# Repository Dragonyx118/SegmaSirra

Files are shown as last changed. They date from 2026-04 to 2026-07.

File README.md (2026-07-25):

# 🌿 SegmaSirra — Smart Solar Greenhouse

<p align="center">
<b>Un'ecosistema IoT completo per la gestione, l'irrigazione e il monitoraggio remoto di una serra automatizzata e autosufficiente.</b>
</p>

<p align="center">





</p>

<br />

<p align="center">
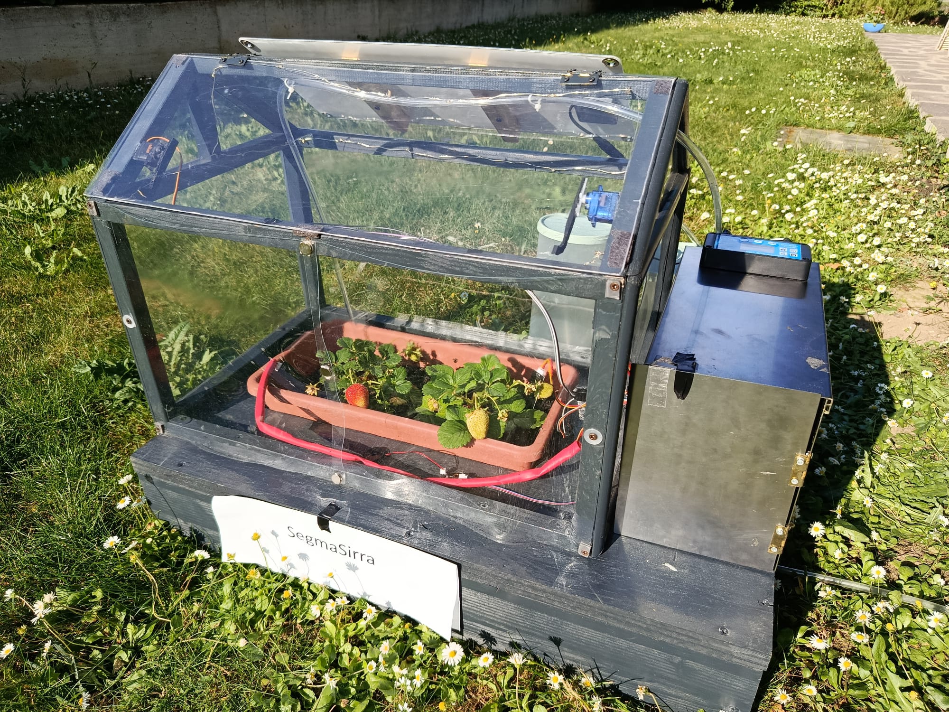
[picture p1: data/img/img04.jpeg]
SegmaSirra Main Overview

</p>

---

## 📌 Indice
- [Cos'è SegmaSirra?](#-cosè-segmasirra)
- [Galleria Fotografica](#-galleria-fotografica)
- [Architettura del Sistema](#-architettura-del-sistema)
- [Specifiche Hardware](#-specifiche-hardware)
- [Funzionalità nel Dettaglio](#-funzionalità-nel-dettaglio)
- [Struttura della Repository](#-struttura-della-repository)
- [Guida all'Installazione](#-guida-allinstallazione)
- [1. Firmware (ESP32)](#1-firmware-esp32)
- [2. App Android](#2-app-android)
- [Roadmap & Sviluppi Futuri](#-roadmap--sviluppi-futuri)
- [Licenza](#-licenza)

---

## 🍃 Cos'è SegmaSirra?

**SegmaSirra** è una serra domotica completamente **autosufficiente dal punto di vista energetico**, progettata per ottimizzare la crescita delle piante senza richiedere interventi umani continui.
**SegmaSirra** è una serra domotica completamente **autosufficiente**, progettata per ottimizzare la crescita delle piante senza richiedere interventi umani continui.

Grazie al microcontrollore **ESP32-WROOM-32** e all'alimentazione integrata da pannello solare a 12V, il sistema analizza costantemente i parametri ambientali (temperatura, umidità del suolo e dell'aria, luminosità) ed esegue azioni correttive automatiche. Tutto l'ecosistema è interfacciato in tempo reale con un'app Android dedicata tramite connessione Wi-Fi.

🌐 **Sito del Progetto:** [dragonyx118.github.io/SegmaSirra-Web/](https://dragonyx118.github.io/SegmaSirra-Web/)

---

## 📱 App Android (SegmaIpp)

Il controllo e il monitoraggio remoto della serra avvengono tramite un'applicazione Android sviluppata ad hoc e ospitata in una repository dedicata:

👉 **Repository dell'App:** [**Dragonyx118/SegmaIpp**](https://github.com/Dragonyx118/SegmaIpp)

### Caratteristiche dell'App:
* **Dashboard in tempo reale:** Visualizzazione dei dati di temperatura, umidità ambientale, umidità del terreno e luminosità.
* **Controllo remoto manuale:** Attivazione forzata dell'irrigazione, gestione delle luci notturne ed apertura/chiusura del tetto via Wi-Fi.
* **Notifiche ed avvisi:** Monitoraggio dello stato delle cisterne e della batteria.

---

## 📸 Galleria Fotografica
## 📸 Galleria

<div align="center">
<table>
<tr>
 <td align="center" width="50%">
   <br />
   <b></b>
 </td>
 <td align="center" width="50%">
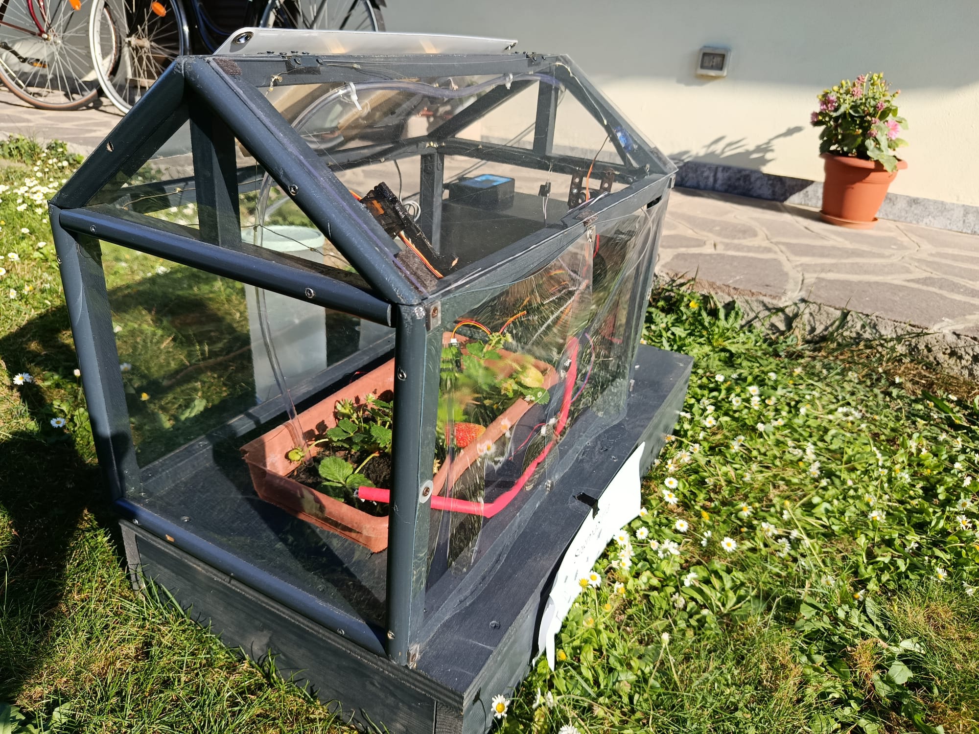
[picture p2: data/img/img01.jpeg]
   <br />
   <b></b>
 </td>
</tr>
<tr>
 <td align="center" width="50%">
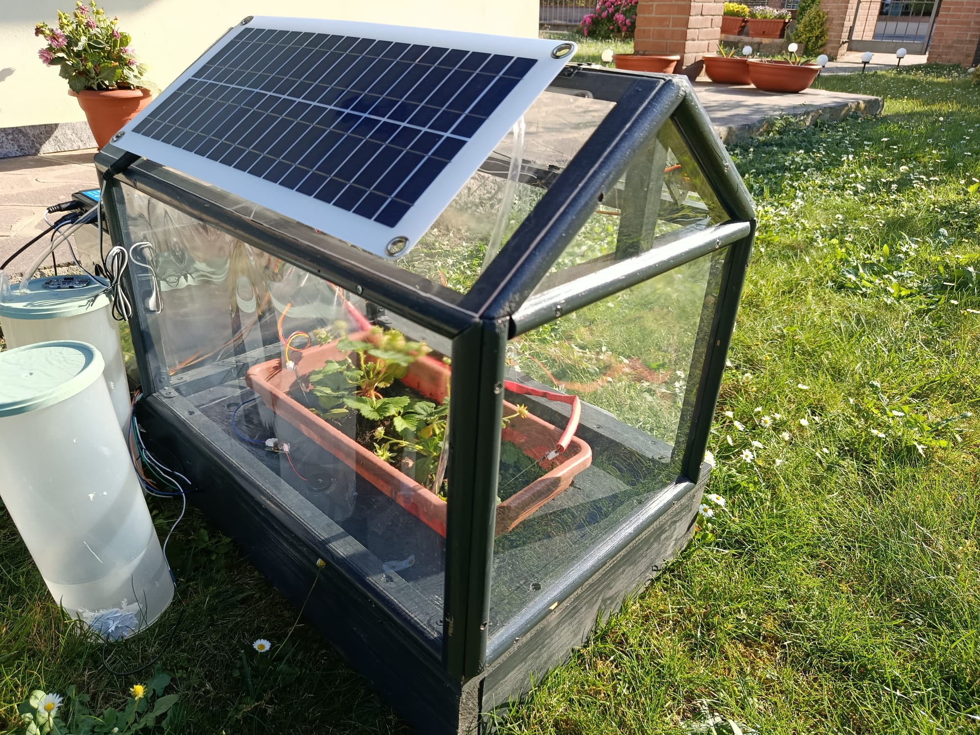
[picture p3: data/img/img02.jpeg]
   <br />
   <b></b>
 </td>
 <td align="center" width="50%">
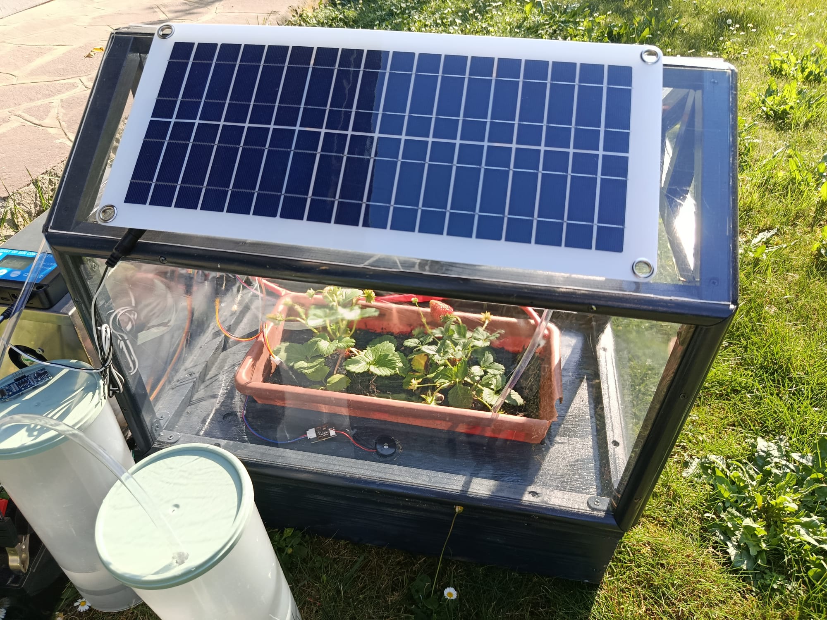
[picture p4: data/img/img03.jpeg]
   <br />
   <b></b>
 </td>
</tr>
</table>
</div>

---

## ⚡ Architettura del Sistema

```text
              +----------------------------------+
              |     Pannello Solare + Reg.      |
              +-----------------+----------------+
                                |
                                v
                      +------------------+
                      | Batteria AGM 12V |
                      +--------+---------+
                                |
                                v
+--------------------------------+--------------------------------+
|                       Modulo ESP32-WROOM-32                      |
|                                                                 |
|  [Sensori Clima & Luce]  --->  Elaborazione Data  --->  [Wi-Fi] |
+-------+------------------------+------------------------+-------+
       |                        |                        |
       v                        v                        v
+---------------+        +---------------+        +---------------+
|   Attuatori   |        | Servomotori   |        |  App Android  |
| 2x Ventole    |        | Apertura      |        | Monitoraggio  |
| 2x Pompe 12V  |        | Tetto         |        |  & Comandi    |
| Luci Notturne |        +---------------+        +---------------+

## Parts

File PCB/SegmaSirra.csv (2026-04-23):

Reference | Qty | Value | DNP | Exclude from BOM | Exclude from Board | Footprint | Datasheet
C1 | 1 | 100nF |  |  |  | Capacitor_THT:C_Disc_D5.0mm_W2.5mm_P5.00mm | ~
C2 | 1 | 470µF 16V |  |  |  | Capacitor_THT:CP_Radial_D8.0mm_P3.50mm | ~
D1 | 1 | LED |  |  |  | LED_THT:LED_D5.0mm | ~
D2 | 1 | D |  |  |  | Diode_THT:D_5KPW_P12.70mm_Horizontal | ~
J1 | 1 | 12V out |  |  |  | TerminalBlock_Phoenix:TerminalBlock_Phoenix_MKDS-1,5-2_1x02_P5.00mm_Horizontal | ~
J2 | 1 | ScocketEsp32 (1) |  |  |  | Connector_PinSocket_2.54mm:PinSocket_1x19_P2.54mm_Vertical | ~
J3 | 1 | ScocketEsp32 (2) |  |  |  | Connector_PinSocket_2.54mm:PinSocket_1x19_P2.54mm_Vertical | ~
J4 | 1 | 12V in |  |  |  | TerminalBlock_Phoenix:TerminalBlock_Phoenix_MKDS-1,5-2_1x02_P5.00mm_Horizontal | ~
J5 | 1 | 5V out |  |  |  | TerminalBlock_Phoenix:TerminalBlock_Phoenix_MKDS-1,5-2_1x02_P5.00mm_Horizontal | ~
J6 | 1 | Servo1 |  |  |  | Connector_PinSocket_2.54mm:PinSocket_1x03_P2.54mm_Vertical | ~
J7 | 1 | Servo2 |  |  |  | Connector_PinSocket_2.54mm:PinSocket_1x03_P2.54mm_Vertical | ~
J8 | 1 | Umidif1 |  |  |  | Connector_PinSocket_2.54mm:PinSocket_1x03_P2.54mm_Vertical | ~
J9 | 1 | Umidif2 |  |  |  | Connector_PinSocket_2.54mm:PinSocket_1x03_P2.54mm_Vertical | ~
J10 | 1 | ConPompLedCOM |  |  |  | TerminalBlock_Phoenix:TerminalBlock_Phoenix_MKDS-1,5-3_1x03_P5.00mm_Horizontal | ~
J11 | 1 | Conn Vent2 |  |  |  | Connector_JST:JST_PH_B2B-PH-K_1x02_P2.00mm_Vertical | ~
J12 | 1 | Conn Vent1 |  |  |  | Connector_JST:JST_PH_B2B-PH-K_1x02_P2.00mm_Vertical | ~
J13 | 1 | connettore fotoresistore |  |  |  | Connector_PinSocket_2.54mm:PinSocket_1x02_P2.54mm_Vertical | ~
J14 | 1 | ConnSensUltra |  |  |  | Connector_PinSocket_2.54mm:PinSocket_1x04_P2.54mm_Vertical | ~
J15 | 1 | SchermoLCDi2C |  |  |  | Connector_PinSocket_2.54mm:PinSocket_1x04_P2.54mm_Vertical | ~
J16 | 1 | SensTerreno1 |  |  |  | Connector_PinSocket_2.54mm:PinSocket_1x03_P2.54mm_Vertical | ~
J17 | 1 | SensTerreno2 |  |  |  | Connector_PinSocket_2.54mm:PinSocket_1x03_P2.54mm_Vertical | ~
J18 | 1 | Pompa 2 |  |  |  | TerminalBlock_Phoenix:TerminalBlock_Phoenix_MKDS-1,5-2_1x02_P5.00mm_Horizontal | ~
J19 | 1 | ConnRelè |  |  |  | TerminalBlock_Phoenix:TerminalBlock_Phoenix_MKDS-1,5-4_1x04_P5.00mm_Horizontal | ~
J20 | 1 | SHT35 |  |  |  | Connector_PinSocket_2.54mm:PinSocket_1x04_P2.54mm_Vertical | ~
J21 | 1 | USB_A |  |  |  | Connector_PinHeader_2.54mm:PinHeader_1x04_P2.54mm_Vertical | ~
Q1 | 1 | IRLZ44N |  |  |  | Package_TO_SOT_THT:TO-220-3_Vertical | http://www.irf.com/product-info/datasheets/data/irlz44n.pdf
R1 | 1 | 220 Ohm |  |  |  | Resistor_THT:R_Axial_DIN0207_L6.3mm_D2.5mm_P7.62mm_Horizontal | ~
R2 | 1 | 100 ohm |  |  |  | Resistor_THT:R_Axial_DIN0207_L6.3mm_D2.5mm_P7.62mm_Horizontal | ~
R3 | 1 | 10k Ohm |  |  |  | Resistor_THT:R_Axial_DIN0207_L6.3mm_D2.5mm_P7.62mm_Horizontal | ~
R4 | 1 | 10kOhm |  |  |  | Resistor_THT:R_Axial_DIN0207_L6.3mm_D2.5mm_P7.62mm_Horizontal | ~
R5 | 1 | 4,7k / 10k Ohm |  |  |  | Resistor_THT:R_Axial_DIN0207_L6.3mm_D2.5mm_P7.62mm_Horizontal | ~
SW1 | 1 | SW_SPDT |  |  |  | Button_Switch_THT:SW_Slide-03_Wuerth-WS-SLTV_10x2.5x6.4_P2.54mm | ~
TP1 | 1 | GND |  |  |  | TestPoint:TestPoint_Pad_D1.5mm | ~
TP2 | 1 | 12V |  |  |  | TestPoint:TestPoint_Pad_D1.5mm | ~
TP3 | 1 | 5V |  |  |  | TestPoint:TestPoint_Pad_D1.5mm | ~
U1 | 1 | DHT11 |  |  |  | Sensor:Aosong_DHT11_5.5x12.0_P2.54mm | http://akizukidenshi.com/download/ds/aosong/DHT11.pdf

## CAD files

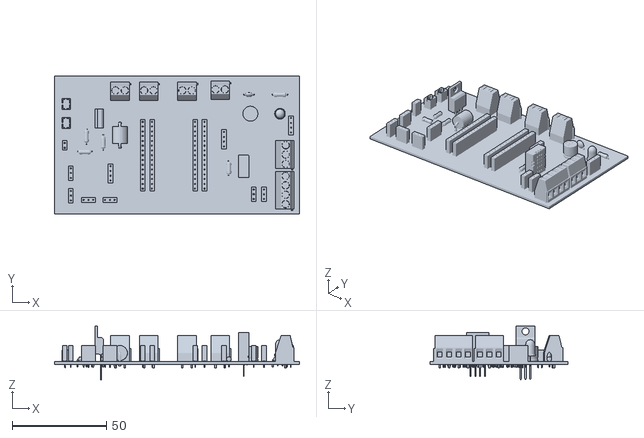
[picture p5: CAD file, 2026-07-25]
PCB/SegmaSirra.stl
130.3 x 73.4 x 28.5

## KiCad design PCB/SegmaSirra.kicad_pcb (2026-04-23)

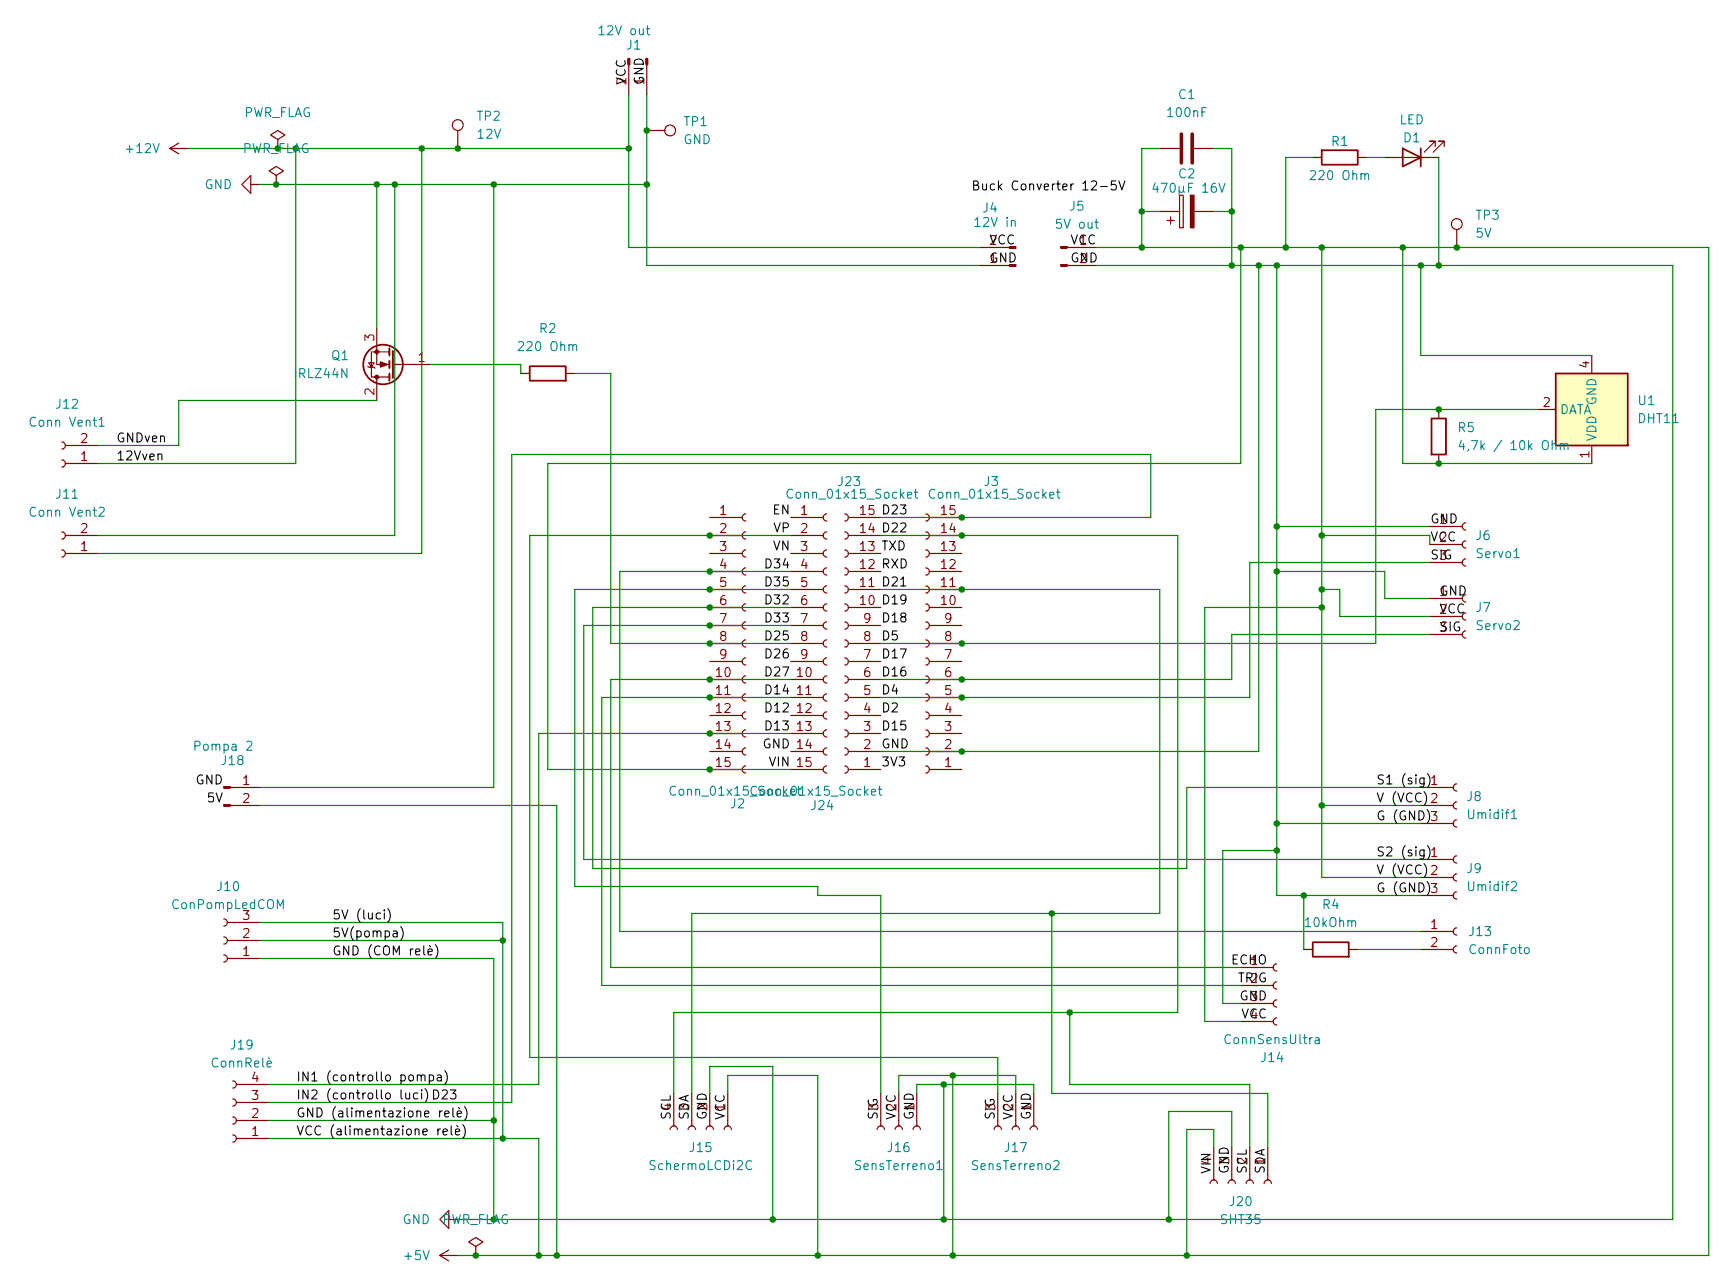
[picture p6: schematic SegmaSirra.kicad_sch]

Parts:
C1: 100nF; C_Disc_D5.0mm_W2.5mm_P5.00mm
C2: 470µF 16V; CP_Radial_D8.0mm_P3.50mm
D1: LED; LED_D5.0mm
J1: 12V out; TerminalBlock_Phoenix_MKDS-1,5-2_1x02_P5.00mm_Horizontal
J2, J3, J23, J24: Conn_01x15_Socket; PinSocket_1x15_P2.54mm_Vertical
J4: 12V in; TerminalBlock_Phoenix_MKDS-1,5-2_1x02_P5.00mm_Horizontal
J5: 5V out; TerminalBlock_Phoenix_MKDS-1,5-2_1x02_P5.00mm_Horizontal
J6: Servo1; PinSocket_1x03_P2.54mm_Vertical
J7: Servo2; PinSocket_1x03_P2.54mm_Vertical
J8: Umidif1; PinSocket_1x03_P2.54mm_Vertical
J9: Umidif2; PinSocket_1x03_P2.54mm_Vertical
J10: ConPompLedCOM; TerminalBlock_Phoenix_MKDS-1,5-3_1x03_P5.00mm_Horizontal
J11: Conn Vent2; JST_PH_B2B-PH-K_1x02_P2.00mm_Vertical
J12: Conn Vent1; JST_PH_B2B-PH-K_1x02_P2.00mm_Vertical
J13: ConnFoto; PinSocket_1x02_P2.54mm_Vertical
J14: ConnSensUltra; PinSocket_1x04_P2.54mm_Vertical
J15: SchermoLCDi2C; PinSocket_1x04_P2.54mm_Vertical
J16: SensTerreno1; PinSocket_1x03_P2.54mm_Vertical
J17: SensTerreno2; PinSocket_1x03_P2.54mm_Vertical
J18: Pompa 2; TerminalBlock_Phoenix_MKDS-1,5-2_1x02_P5.00mm_Horizontal
J19: ConnRelè; TerminalBlock_Phoenix_MKDS-1,5-4_1x04_P5.00mm_Horizontal
J20: SHT35; PinSocket_1x04_P2.54mm_Vertical
Q1: IRLZ44N; TO-220-3_Vertical
R1, R2: 220 Ohm; R_Axial_DIN0207_L6.3mm_D2.5mm_P7.62mm_Horizontal
R4: 10kOhm; R_Axial_DIN0207_L6.3mm_D2.5mm_P7.62mm_Horizontal
R5: 4,7k / 10k Ohm; R_Axial_DIN0207_L6.3mm_D2.5mm_P7.62mm_Horizontal
TP1: GND; TestPoint_Pad_D1.5mm
TP2: 12V; TestPoint_Pad_D1.5mm
TP3: 5V; TestPoint_Pad_D1.5mm
U1: DHT11; Aosong_DHT11_5.5x12.0_P2.54mm

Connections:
+5V: C1.1, C2.1, J2.15, J5.1, J6.2, J7.2, J8.2, J9.2, J10.2, J10.3, J14.4, J15.1, J16.2, J17.2, J18.2, J19.1, J20.4, J24.15, R1.2, R5.2, TP3.1, U1.1 (VDD)
+12V: J1.2, J4.2, J11.1, J12.1, TP2.1
/3V3: J23.1
/D2: J23.4
/D4: J3.5, J6.3, J23.5
/D5: J3.8, J23.8, R5.1, U1.2 (DATA)
/D12: J24.12
/D13: J2.13, J19.4, J24.13
/D14: J2.11, J14.2, J24.11
/D15: J23.3
/D16: J3.6, J7.3, J23.6
/D17: J23.7
/D18: J23.9
/D19: J23.10
/D21: J3.11, J15.3, J20.1, J23.11
/D22: J3.14, J15.4, J20.2, J23.14
/D23: J3.15, J19.3, J23.15
/D25: J2.8, J24.8, R2.2
/D26: J24.9
/D27: J2.10, J14.1, J24.10
/D32: J2.6, J8.1, J24.6
/D33: J2.7, J9.1, J24.7
/D34: J2.4, J13.1, J24.4
/D35: J2.5, J16.3, J24.5
/EN: J24.1
/GNDven: J12.2, Q1.2 (D)
/RXD: J23.12
/TXD: J23.13
/VN: J24.3
/VP: J2.2, J17.3, J24.2
GND: C1.2, C2.2, D1.1 (K), J1.1, J3.2, J4.1, J5.2, J6.1, J7.1, J8.3, J9.3, J10.1, J11.2, J14.3, J15.2, J16.1, J17.1, J18.1, J19.2, J20.3, J23.2, J24.14, Q1.3 (S), R4.1, TP1.1, U1.4 (GND)
unnamed: D1.2 (A), R1.1
unnamed: J13.2, R4.2
unnamed: Q1.1 (G), R2.1

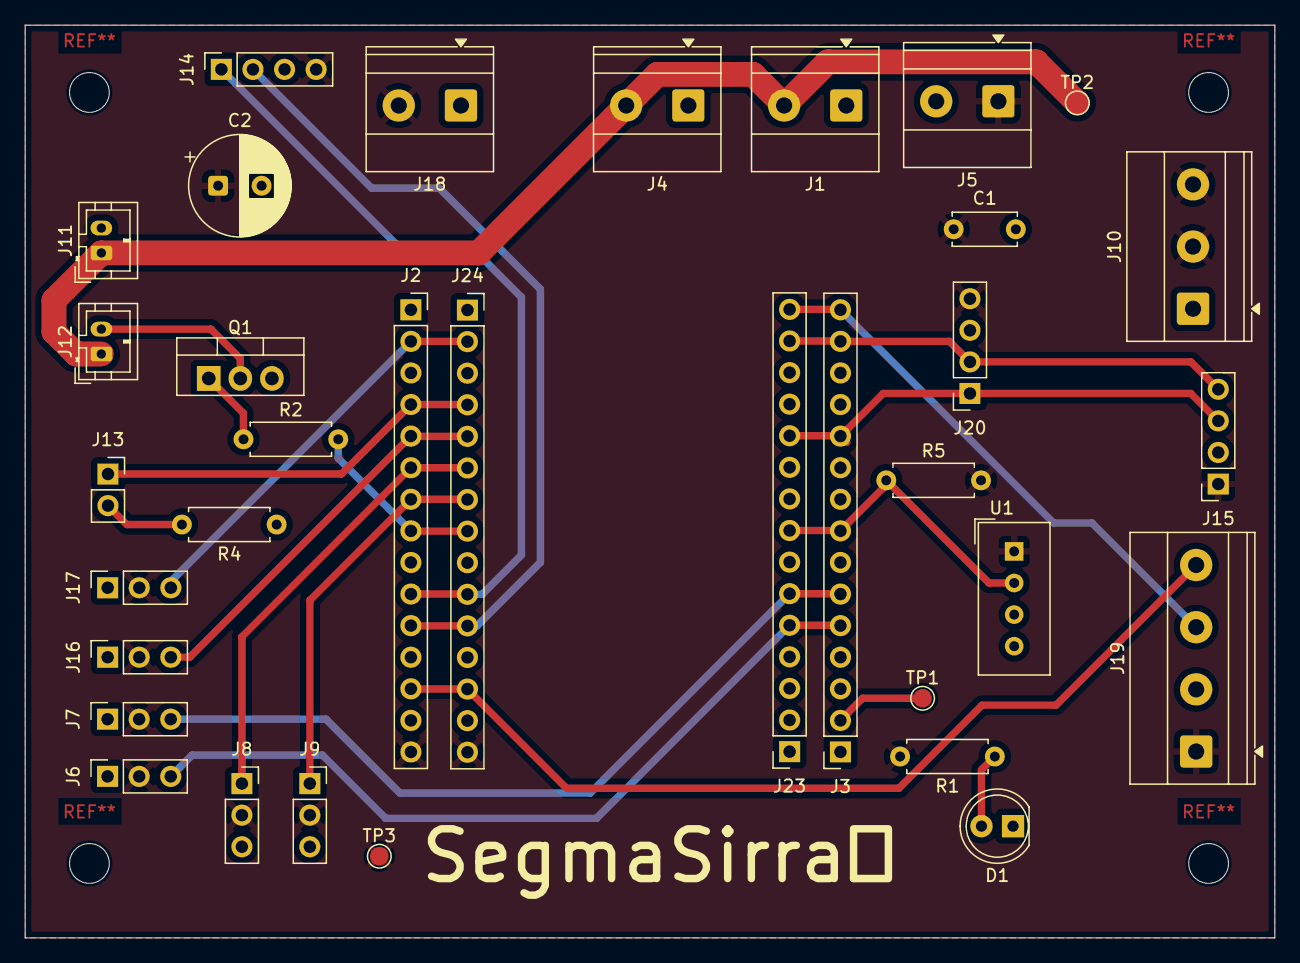
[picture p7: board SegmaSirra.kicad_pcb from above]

Board: 2 copper layers, 100.5 x 73.4 mm, 34 parts (0 on the bottom side), 22 nets.

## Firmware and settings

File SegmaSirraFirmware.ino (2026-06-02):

// ============================================================
// SegmaSirra -6.7 V senza delay bloccanti
// DEBUG VERSION — ultrasuoni con pulseIn (funzionante) ogni 7s
// MODIFICA: servo tetto con movimento graduale (~2s) via FreeRTOS
// ============================================================

#include <Arduino.h>
#include <ESP32Servo.h>
#include <Wire.h>
#include <LiquidCrystal_I2C.h>
#include <WiFi.h>
#include <HTTPClient.h>
#include <DHT.h>
#include <ArduinoJson.h>
#include <Adafruit_SHT4x.h>

// ============================================================
// --- DEBUG CONFIG ---
// ============================================================
#define DEBUG_ULTRASUONI   true
#define DEBUG_SENSORI      true
#define DEBUG_FIREBASE     true
#define DEBUG_WIFI         true
#define DEBUG_ATTUATORI    true
#define DEBUG_LCD          false
#define DEBUG_LOOP_TIMING  false

#define DBG_US(...)   do { if (DEBUG_ULTRASUONI) { Serial.print("[US]   "); Serial.printf(__VA_ARGS__); } } while(0)
#define DBG_SEN(...)  do { if (DEBUG_SENSORI)    { Serial.print("[SEN]  "); Serial.printf(__VA_ARGS__); } } while(0)
#define DBG_FB(...)   do { if (DEBUG_FIREBASE)   { Serial.print("[FB]   "); Serial.printf(__VA_ARGS__); } } while(0)
#define DBG_WIFI(...) do { if (DEBUG_WIFI)       { Serial.print("[WIFI] "); Serial.printf(__VA_ARGS__); } } while(0)
#define DBG_ATT(...)  do { if (DEBUG_ATTUATORI)  { Serial.print("[ATT]  "); Serial.printf(__VA_ARGS__); } } while(0)
#define DBG_LCD(...)  do { if (DEBUG_LCD)        { Serial.print("[LCD]  "); Serial.printf(__VA_ARGS__); } } while(0)
#define DBG_LOOP(...) do { if (DEBUG_LOOP_TIMING){ Serial.print("[LOOP] "); Serial.printf(__VA_ARGS__); } } while(0)

// --- COSTANTI FISICHE ---
const float VELOCITA_SUONO_CM_US = 0.034f;
const float TANK_HEIGHT          = 21.37f;
const float SOGLIA_ACQUA_MINIMA  = 10.0f;

// --- COSTANTI CALIBRAZIONE ACQUA ---
const float DIST_PIENA = 4.56f;    // cm quando tanica piena
const float DIST_VUOTA = 16.37f;   // cm quando rimangono 5cm (= 0% utile)

// --- COSTANTI TIMING (ms) ---
const unsigned long INTERVALLO_SENSORI    = 500;
const unsigned long INTERVALLO_LCD        = 3000;
const unsigned long INTERVALLO_FIREBASE   = 1000;
const unsigned long INTERVALLO_COMANDI    = 500;
const unsigned long INTERVALLO_WIFI_CHECK = 30000;
const unsigned long DHT_WARMUP_MS        = 2000;

// --- ULTRASUONI ---
const unsigned long INTERVALLO_ULTRASUONI = 7000;
const int           CAMPIONI_ULTRASUONI   = 3;
const unsigned long PULSIN_TIMEOUT_US     = 30000;
const unsigned long PAUSA_TRA_PING_MS     = 50;

// --- SERVO TETTO ---
// Aperto:  servoA (pin 4) = 90°,  servoB (pin 16) = 90°
// Chiuso:  servoA (pin 4) = 0°,   servoB (pin 16) = 180°
const int SERVO_A_APERTO  = 0;
const int SERVO_B_APERTO  = 180;
const int SERVO_A_CHIUSO  = 90;
const int SERVO_B_CHIUSO  = 90;
// Durata totale del movimento in ms (~2 secondi).
// Con 90 step massimi da 1° e SERVO_STEP_DELAY_MS = 22ms -> 90 * 22 = 1980ms ≈ 2s
const unsigned long SERVO_STEP_DELAY_MS = 22;

// --- PESI MEDIA PONDERATA TEMP/HUM ---
const float PESO_DHT = 0.3f;
const float PESO_SHT = 0.7f;

// --- CALIBRAZIONE LUCE ---
const int LUCE_MIN = 2000;
const int LUCE_MAX = 4095;

// --- PIN ---
const int luci            = 23;
const int sensoreTerreno  = 35;
const int sensoreTerreno2 = 36;
const int trigPin         = 14;
const int echoPin         = 27;
const int lightPin        = 34;
const int umidificatore1  = 32;
const int umidificatore2  = 33;
const int ventolaSerra    = 25;
const int ventolaScatola  = 26;
const int pompa2          = 13;

// ============================================================
// --- VARIABILI GLOBALI ---
// ============================================================

struct SensorData {
    float temperature;
    float humidity;
    int   soilMoisture;
    bool  valid;
};
SensorData lastSensorData = { -99.0f, -99.0f, 0, false };
float      lastWaterLevel = -1.0f;
int        lastLightPct   = 0;

unsigned long loopCount  = 0;
unsigned long usAvvii    = 0;
unsigned long usSuccessi = 0;
unsigned long usErrori   = 0;
unsigned long fbInvii    = 0;
unsigned long fbErrori   = 0;

unsigned long lastSensorRead    = 0;
unsigned long lastDisplayUpdate = 0;
unsigned long lastSendData      = 0;
unsigned long lastCommandCheck  = 0;
unsigned long lastWifiCheck     = 0;

bool roofOpen = false;

// --- Task servo: stato condiviso ---
// servoTargetOpen viene scritto dal loop, letto dal task servo.
// volatile + SemaphoreHandle per accesso sicuro inter-task.
volatile bool servoTargetOpen    = false;  // posizione target richiesta
volatile bool servoMoving        = false;  // true mentre il task sta muovendo
SemaphoreHandle_t servoMutex     = NULL;

#define DHTPIN  5
#define DHTTYPE DHT11
DHT dht(DHTPIN, DHTTYPE);
unsigned long dhtReadyAt = 0;

Adafruit_SHT4x sht45 = Adafruit_SHT4x();
bool sht45Ok = false;

Servo servoA;
Servo servoB;
const int servoAPin = 4;
const int servoBPin = 16;

#define LCD_ADDR 0x27
LiquidCrystal_I2C lcd(LCD_ADDR, 16, 2);

const char* ssid               = "LAPTOP1234";
const char* password           = "12345678";
const char* firebaseCmdUrl     = "https://serra-d44cc-default-rtdb.europe-west1.firebasedatabase.app/serra/commands.json";
const char* firebaseSensorsUrl = "https://serra-d44cc-default-rtdb.europe-west1.firebasedatabase.app/serra/sensors.json";

// ============================================================
// --- WIFI SM ---
// ============================================================
enum WiFiStato {
    WIFI_OK, WIFI_RECONNECTING, WIFI_FALLBACK_SCAN,
    WIFI_FALLBACK_WAIT_SSID, WIFI_FALLBACK_WAIT_PASS, WIFI_FALLBACK_CONNECTING
};
struct WiFiSM {
    WiFiStato     stato         = WIFI_OK;
    int           tentativi     = 0;
    unsigned long tStato        = 0;
    String        nuovoSSID     = "";
    String        nuovaPassword = "";
} wifiSM;

// ============================================================
// --- TASK FREERTOS: ULTRASUONI (Core 0) ---
// ============================================================
TaskHandle_t taskUltrasuoniHandle = NULL;

void taskUltrasuoni(void* param) {
    DBG_US("Task avviato su Core %d\n", xPortGetCoreID());
    for (;;) {
        vTaskDelay(pdMS_TO_TICKS(INTERVALLO_ULTRASUONI));

        usAvvii++;
        float somma = 0.0f;
        int   validi = 0;

        DBG_US("--- Inizio misura #%lu (campioni=%d) ---\n", usAvvii, CAMPIONI_ULTRASUONI);

        for (int i = 0; i < CAMPIONI_ULTRASUONI; i++) {
            digitalWrite(trigPin, LOW);
            delayMicroseconds(4);
            digitalWrite(trigPin, HIGH);
            delayMicroseconds(10);
            digitalWrite(trigPin, LOW);

            long duration = pulseIn(echoPin, HIGH, PULSIN_TIMEOUT_US);

            if (duration == 0) {
                DBG_US("  Campione %d/%d: TIMEOUT\n", i + 1, CAMPIONI_ULTRASUONI);
            } else {
                float dist   = duration * VELOCITA_SUONO_CM_US / 2.0f;
                float livello = constrain(
                    (DIST_VUOTA - dist) / (DIST_VUOTA - DIST_PIENA) * 100.0f,
                    0.0f, 100.0f
                );
                somma += livello;
                validi++;
                DBG_US("  Campione %d/%d: %ldus -> %.1fcm -> %.1f%%\n",
                       i + 1, CAMPIONI_ULTRASUONI, duration, dist, livello);
            }

            if (i < CAMPIONI_ULTRASUONI - 1) {
                vTaskDelay(pdMS_TO_TICKS(PAUSA_TRA_PING_MS));
            }
        }

        if (validi > 0) {
            lastWaterLevel = somma / validi;
            usSuccessi++;
            DBG_US("OK: media=%.1f%% (%d/%d validi) [tot ok=%lu err=%lu]\n",
                   lastWaterLevel, validi, CAMPIONI_ULTRASUONI, usSuccessi, usErrori);
        } else {
            usErrori++;
            lastWaterLevel = -1.0f;
            DBG_US("ERRORE: 0 campioni validi [tot ok=%lu err=%lu]\n", usSuccessi, usErrori);
        }
    }
}

// ============================================================
// --- TASK FREERTOS: SERVO TETTO (Core 1) ---
//
// Gira su Core 1 insieme al loop, ma con priorità 2 (loop ha 1).
// Aspetta una notifica dal loop tramite xTaskNotifyGive().
// Quando riceve la notifica legge servoTargetOpen e muove i servo
// gradualmente step da 1° con delay di SERVO_STEP_DELAY_MS ms.
// Il loop non viene bloccato perché il delay è interno al task.
// ============================================================
TaskHandle_t taskServoHandle = NULL;

void taskServo(void* param) {
    DBG_ATT("Task servo avviato su Core %d\n", xPortGetCoreID());

    // Posizione corrente stimata (inizializzata su chiuso)
    int posA = SERVO_A_CHIUSO;
    int posB = SERVO_B_CHIUSO;

    for (;;) {
        // Aspetta finché il loop chiama xTaskNotifyGive(taskServoHandle)
        ulTaskNotifyTake(pdTRUE, portMAX_DELAY);

        // Leggi target con mutex
        bool targetOpen;
        xSemaphoreTake(servoMutex, portMAX_DELAY);
        targetOpen   = servoTargetOpen;
        servoMoving  = true;
        xSemaphoreGive(servoMutex);

        int targetA = targetOpen ? SERVO_A_APERTO : SERVO_A_CHIUSO;
        int targetB = targetOpen ? SERVO_B_APERTO : SERVO_B_CHIUSO;

        DBG_ATT("Servo: movimento %s | A: %d->%d  B: %d->%d\n",
                targetOpen ? "APERTO" : "CHIUSO", posA, targetA, posB, targetB);

        // Calcola quanti step servono (max tra i due servo)
        int stepsA = abs(targetA - posA);
        int stepsB = abs(targetB - posB);
        int steps  = max(stepsA, stepsB);

        for (int i = 1; i <= steps; i++) {
            // Interpolazione lineare per entrambi i servo
            // Usa arrotondamento corretto per evitare jitter all'ultimo step
            int newA = posA + (int)roundf((float)(targetA - posA) * i / steps);
            int newB = posB + (int)roundf((float)(targetB - posB) * i / steps);

            servoA.write(newA);
            servoB.write(newB);

            // Delay non bloccante per il task (non tocca il loop)
            vTaskDelay(pdMS_TO_TICKS(SERVO_STEP_DELAY_MS));

            // Se nel frattempo è arrivato un nuovo target, interrompi
            // e lascia che il task riparta con il nuovo valore
            if (ulTaskNotifyTake(pdTRUE, 0) > 0) {
                // Aggiorna posizione corrente al punto dove ci siamo fermati
                posA = newA;
                posB = newB;
                DBG_ATT("Servo: movimento interrotto a step %d/%d (nuovo comando)\n", i, steps);
                // Re-inserisci la notifica così il for esterno la riceve
                xTaskNotifyGive(taskServoHandle);
                goto next_command;
            }
        }

        // Movimento completato: scrivi esattamente il target
        servoA.write(targetA);
        servoB.write(targetB);
        posA = targetA;
        posB = targetB;
        DBG_ATT("Servo: %s completato (A=%d B=%d)\n",
                targetOpen ? "APERTO" : "CHIUSO", posA, posB);

        next_command:
        xSemaphoreTake(servoMutex, portMAX_DELAY);
        servoMoving = false;
        xSemaphoreGive(servoMutex);
    }
}

// ============================================================
// --- FUNZIONE HELPER: richiedi movimento tetto ---
// Chiamala al posto di servoA.write() / servoB.write() diretto.
// È thread-safe e non bloccante.
// ============================================================
void setRoof(bool open) {
    xSemaphoreTake(servoMutex, portMAX_DELAY);
    servoTargetOpen = open;
    xSemaphoreGive(servoMutex);

    // Notifica il task servo di muoversi
    xTaskNotifyGive(taskServoHandle);

    // Aggiorna subito lo stato logico (non aspettare il completamento fisico)
    roofOpen = open;
    DBG_ATT("Tetto: richiesta %s\n", open ? "APERTURA" : "CHIUSURA");
}

// ============================================================
// --- PROTOTIPI ---
// ============================================================
void connectWiFiBlocking();
void tickWiFiSM();
void sendToFirebase(const SensorData& s, float waterLevel, int lightPct);
void updateLCD(float umiditaTerreno, float acqua, float temp, float umidita, int luce);
void readFirebaseCommands();
void startIrrigation(float waterLevel);
void stopIrrigation();
void startHumidifier();
void stopHumidifier();
void startFan();
void stopFan();
SensorData readNewSensors();
void printDebugSummary();
void scanI2C();
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
void loop() {
    unsigned long now = millis();
    loopCount++;

    tickWiFiSM();

    if (now - lastWifiCheck >= INTERVALLO_WIFI_CHECK) {
        lastWifiCheck = now;
        if (WiFi.status() != WL_CONNECTED && wifiSM.stato == WIFI_OK) {
            DBG_WIFI("Connessione persa!\n");
            WiFi.disconnect();
            WiFi.begin(ssid, password);
            wifiSM.stato     = WIFI_RECONNECTING;
            wifiSM.tentativi = 0;
            wifiSM.tStato    = now;
        } else if (WiFi.status() == WL_CONNECTED) {
            DBG_WIFI("Check OK - IP:%s RSSI:%ddBm heap:%d\n",
                     WiFi.localIP().toString().c_str(), WiFi.RSSI(), ESP.getFreeHeap());
        }
    }

    if (now - lastSensorRead >= INTERVALLO_SENSORI) {
        lastSensorRead = now;
        lastSensorData = readNewSensors();

        int luceRaw = analogRead(lightPin);
        lastLightPct = constrain(
            (int)((float)(luceRaw - LUCE_MIN) / (LUCE_MAX - LUCE_MIN) * 100.0f),
            0, 100
        );
        DBG_SEN("Luce: raw=%d -> %d%%\n", luceRaw, lastLightPct);
    }

    if (now - lastDisplayUpdate >= INTERVALLO_LCD) {
        lastDisplayUpdate = now;
        updateLCD(lastSensorData.soilMoisture, lastWaterLevel,
                  lastSensorData.temperature, lastSensorData.humidity, lastLightPct);
        printDebugSummary();
    }

    if (now - lastSendData >= INTERVALLO_FIREBASE) {
        lastSendData = now;
        sendToFirebase(lastSensorData, lastWaterLevel, lastLightPct);
    }

    if (now - lastCommandCheck >= INTERVALLO_COMANDI) {
        lastCommandCheck = now;
        readFirebaseCommands();
    }

    DBG_LOOP("loop #%lu heap=%d\n", loopCount, ESP.getFreeHeap());
}

// ============================================================
// --- RIEPILOGO DEBUG ---
// ============================================================
void printDebugSummary() {
    bool moving;
    xSemaphoreTake(servoMutex, portMAX_DELAY);
    moving = servoMoving;
    xSemaphoreGive(servoMutex);

    Serial.println("\n========== RIEPILOGO ==========");
    Serial.printf("  Uptime: %lus  Loop: %lu  Heap: %d\n",
                  millis() / 1000, loopCount, ESP.getFreeHeap());
    Serial.println("  SENSORI:");
    if (lastSensorData.valid) {
        Serial.printf("    T=%.1f°C  H=%.1f%%\n",
                      lastSensorData.temperature, lastSensorData.humidity);
    } else {
        Serial.println("    T/H: ERRORE");
    }
    Serial.printf("    Suolo=%d%%  Luce=%d%%\n", lastSensorData.soilMoisture, lastLightPct);
    if (lastWaterLevel >= 0) {
        Serial.printf("    Acqua=%.1f%%\n", lastWaterLevel);
    } else {
        Serial.println("    Acqua: in attesa prima misura...");
    }
    Serial.printf("  ULTRASUONI: misure=%lu ok=%lu err=%lu (%.0f%%)\n",
                  usAvvii, usSuccessi, usErrori,
                  usAvvii > 0 ? (float)usSuccessi / usAvvii * 100.0f : 0.0f);
    Serial.printf("  WIFI: %s  RSSI:%ddBm\n",
                  WiFi.status() == WL_CONNECTED ? "OK" : "DISCONNESSO", WiFi.RSSI());
    Serial.printf("  FIREBASE: invii=%lu err=%lu\n", fbInvii, fbErrori);
    Serial.printf("  ATTUATORI: pompa=%s umid=%s/%s ventola=%s luci=%s tetto=%s%s\n",
                  digitalRead(pompa2)         ? "ON" : "OFF",
                  digitalRead(umidificatore1) ? "ON" : "OFF",
                  digitalRead(umidificatore2) ? "ON" : "OFF",
                  digitalRead(ventolaSerra)   ? "ON" : "OFF",
                  digitalRead(luci)           ? "ON" : "OFF",
                  roofOpen                    ? "APERTO" : "CHIUSO",
                  moving                      ? " (in movimento...)" : "");
    Serial.println("================================\n");
}

// ============================================================
// --- SCAN I2C ---
// ============================================================
void scanI2C() {
    Serial.println("[I2C] Scansione dispositivi...");
    int trovati = 0;
    for (byte addr = 1; addr < 127; addr++) {
        Wire.beginTransmission(addr);
        if (Wire.endTransmission() == 0) {
            Serial.printf("[I2C] Dispositivo trovato a 0x%02X%s%s\n", addr,
                          (addr == 0x27 || addr == 0x3F) ? " <- LCD"   : "",
                          (addr == 0x44 || addr == 0x45) ? " <- SHT4x" : "");
            trovati++;
        }
    }
    Serial.printf("[I2C] Totale: %d dispositivo/i\n", trovati);
    if (trovati == 0) Serial.println("[I2C] NESSUNO! Verifica SDA=21 SCL=22");
}

// ============================================================
// --- WIFI BLOCKING ---
// ============================================================
void connectWiFiBlocking() {
    DBG_WIFI("Connessione a '%s'...\n", ssid);
    WiFi.begin(ssid, password);
    unsigned long t0 = millis(), tPoll = millis();
    while (WiFi.status() != WL_CONNECTED && millis() - t0 < 10000) {
        if (millis() - tPoll >= 500) { tPoll = millis(); Serial.print("."); }
    }
    if (WiFi.status() == WL_CONNECTED) {
        DBG_WIFI("\nConnesso! IP:%s RSSI:%ddBm\n",
                 WiFi.localIP().toString().c_str(), WiFi.RSSI());
        wifiSM.stato = WIFI_OK;
    } else {
        DBG_WIFI("\nFallito, avvio fallback\n");
        wifiSM.tStato = millis();
        wifiSM.stato  = WIFI_FALLBACK_SCAN;
    }
}

// ============================================================
// --- WIFI SM ---
// ============================================================
void tickWiFiSM() {
    unsigned long now = millis();
    switch (wifiSM.stato) {
        case WIFI_OK: break;
        case WIFI_RECONNECTING:
            if (now - wifiSM.tStato >= 500) {
                wifiSM.tStato = now; wifiSM.tentativi++;
                if (WiFi.status() == WL_CONNECTED) {
                    DBG_WIFI("Riconnesso!\n"); wifiSM.stato = WIFI_OK;
                } else if (wifiSM.tentativi >= 20) {
                    DBG_WIFI("Riconnessione fallita\n"); wifiSM.stato = WIFI_OK;
                }
            }
            break;
        case WIFI_FALLBACK_SCAN: {
            Serial.println("\n=== CONFIGURAZIONE WIFI MANUALE ===");
            int n = WiFi.scanNetworks();
            for (int i = 0; i < n; i++)
                Serial.printf("  %d) %s (%ddBm)\n", i + 1,
                              WiFi.SSID(i).c_str(), WiFi.RSSI(i));
            Serial.println("Inserisci SSID:");
            wifiSM.stato = WIFI_FALLBACK_WAIT_SSID; wifiSM.tStato = now;
            break;
        }
        case WIFI_FALLBACK_WAIT_SSID:
            if (Serial.available()) {
                wifiSM.nuovoSSID = Serial.readStringUntil('\n');
                wifiSM.nuovoSSID.trim();
                if (wifiSM.nuovoSSID.length() > 0) {
                    Serial.println("Inserisci password:");
                    wifiSM.stato = WIFI_FALLBACK_WAIT_PASS; wifiSM.tStato = now;
                }
            }
            break;
        case WIFI_FALLBACK_WAIT_PASS:
            if (Serial.available()) {
                wifiSM.nuovaPassword = Serial.readStringUntil('\n');
                wifiSM.nuovaPassword.trim();
                wifiSM.stato = WIFI_FALLBACK_CONNECTING;
                wifiSM.tStato = now; wifiSM.tentativi = 0;
                if (wifiSM.nuovaPassword.length() > 0)
                    WiFi.begin(wifiSM.nuovoSSID.c_str(), wifiSM.nuovaPassword.c_str());
                else
                    WiFi.begin(wifiSM.nuovoSSID.c_str());
            } else if (now - wifiSM.tStato >= 30000) {
                wifiSM.stato = WIFI_FALLBACK_CONNECTING;
                wifiSM.tStato = now; wifiSM.tentativi = 0;
                WiFi.begin(wifiSM.nuovoSSID.c_str());
            }
            break;
        case WIFI_FALLBACK_CONNECTING:
            if (now - wifiSM.tStato >= 500) {
                wifiSM.tStato = now; wifiSM.tentativi++;
                if (WiFi.status() == WL_CONNECTED) {
                    DBG_WIFI("Connesso!\n"); wifiSM.stato = WIFI_OK;
                } else if (wifiSM.tentativi >= 30) {
                    DBG_WIFI("Offline\n"); wifiSM.stato = WIFI_OK;
                }
            }
            break;
    }
}
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

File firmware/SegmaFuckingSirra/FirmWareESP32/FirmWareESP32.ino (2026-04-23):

// ============================================================
// SegmaFuckingSirra -67.0 V senza delay bloccanti
// ============================================================

// --- LIBRERIE ---
#include <Arduino.h>
#include <ESP32Servo.h>
#include <Wire.h>
#include <LiquidCrystal_I2C.h>
#include <WiFi.h>
#include <HTTPClient.h>
#include <DHT.h>
#include <ArduinoJson.h>
#include <Adafruit_SHT4x.h>

// --- COSTANTI FISICHE ---
const float VELOCITA_SUONO_CM_US = 0.034f;
const float TANK_HEIGHT          = 30.0f;
const float SOGLIA_ACQUA_MINIMA  = 10.0f;

// --- COSTANTI TIMING (ms) ---
const unsigned long INTERVALLO_SENSORI    = 500;
const unsigned long INTERVALLO_LCD        = 3000;
const unsigned long INTERVALLO_FIREBASE   = 1000;
const unsigned long INTERVALLO_COMANDI    = 500;
const unsigned long INTERVALLO_WIFI_CHECK = 30000;
const unsigned long DHT_WARMUP_MS         = 2000;

// --- COSTANTI ULTRASUONI ---
const int           CAMPIONI_ULTRASUONI   = 3;
const unsigned long PAUSA_TRA_PING_MS     = 35;
const unsigned long TIMEOUT_ECHO_MS       = 30;

// --- PESI MEDIA PONDERATA SENSORI T/H ---
const float PESO_DHT = 0.3f;
const float PESO_SHT = 0.7f;

// --- PIN ---
const int luci            = 23;
const int sensoreTerreno  = 35;
const int sensoreTerreno2 = 36;
const int trigPin         = 14;
const int echoPin         = 27;
const int lightPin        = 34;
const int umidificatore1  = 32;
const int umidificatore2  = 33;
const int ventolaSerra    = 25;
const int ventolaScatola  = 26;
const int pompa2          = 13;

// ============================================================
// --- MACCHINA A STATI: ULTRASUONI NON BLOCCANTE ---
// ============================================================
enum UltrasuoniStato {
    US_IDLE,
    US_TRIGGER_LOW,
    US_TRIGGER_HIGH,
    US_WAIT_ECHO_START,
    US_WAIT_ECHO_END,
    US_PAUSA,
    US_DONE
};

struct UltrasuoniSM {
    UltrasuoniStato stato    = US_IDLE;
    int             campione = 0;
    float           somma    = 0.0f;
    int             validi   = 0;
    unsigned long   tStato   = 0;
    float           risultato= -1.0f;
    bool            pronto   = false;
} usSM;

void startUltrasuoni() {
    usSM.stato    = US_TRIGGER_LOW;
    usSM.campione = 0;
    usSM.somma    = 0.0f;
    usSM.validi   = 0;
    usSM.pronto   = false;
    usSM.tStato   = micros();
    digitalWrite(trigPin, LOW);
}

void tickUltrasuoniSM() {
    if (usSM.stato == US_IDLE || usSM.stato == US_DONE) return;

    switch (usSM.stato) {
        case US_TRIGGER_LOW:
            if (micros() - usSM.tStato >= 2) {
                digitalWrite(trigPin, HIGH);
                usSM.tStato = micros();
                usSM.stato  = US_TRIGGER_HIGH;
            }
            break;

        case US_TRIGGER_HIGH:
            if (micros() - usSM.tStato >= 10) {
                digitalWrite(trigPin, LOW);
                usSM.tStato = millis();
                usSM.stato  = US_WAIT_ECHO_START;
            }
            break;

        case US_WAIT_ECHO_START:
            if (digitalRead(echoPin) == HIGH) {
                usSM.tStato = micros();
                usSM.stato  = US_WAIT_ECHO_END;
            } else if (millis() - usSM.tStato >= TIMEOUT_ECHO_MS) {
                usSM.campione++;
                usSM.tStato = millis();
                usSM.stato  = (usSM.campione < CAMPIONI_ULTRASUONI) ? US_PAUSA : US_DONE;
                if (usSM.stato == US_DONE) {
                    usSM.risultato = (usSM.validi > 0) ? usSM.somma / usSM.validi : -1.0f;
                    usSM.pronto    = true;
                    if (usSM.validi == 0) Serial.println("Errore: nessuna lettura valida (ultrasuoni).");
                }
            }
            break;

        case US_WAIT_ECHO_END:
            if (digitalRead(echoPin) == LOW) {
                unsigned long duration = micros() - usSM.tStato;
                float distance = duration * VELOCITA_SUONO_CM_US / 2.0f;
                float livello  = constrain(100.0f - (distance / TANK_HEIGHT * 100.0f), 0.0f, 100.0f);
                usSM.somma += livello;
                usSM.validi++;
                usSM.campione++;
                usSM.tStato = millis();
                usSM.stato  = (usSM.campione < CAMPIONI_ULTRASUONI) ? US_PAUSA : US_DONE;
                if (usSM.stato == US_DONE) {
                    usSM.risultato = usSM.somma / usSM.validi;
                    usSM.pronto    = true;
                }
            } else if (micros() - usSM.tStato > TIMEOUT_ECHO_MS * 1000UL) {
                usSM.campione++;
                usSM.tStato = millis();
                usSM.stato  = (usSM.campione < CAMPIONI_ULTRASUONI) ? US_PAUSA : US_DONE;
                if (usSM.stato == US_DONE) {
                    usSM.risultato = (usSM.validi > 0) ? usSM.somma / usSM.validi : -1.0f;
                    usSM.pronto    = true;
                }
            }
            break;

        case US_PAUSA:
            if (millis() - usSM.tStato >= PAUSA_TRA_PING_MS) {
                digitalWrite(trigPin, LOW);
                usSM.tStato = micros();
                usSM.stato  = US_TRIGGER_LOW;
            }
            break;

        case US_DONE:
        case US_IDLE:
            break;
    }
}

// ============================================================
// --- MACCHINA A STATI: WIFI NON BLOCCANTE ---
// ============================================================
enum WiFiStato {
    WIFI_OK,
    WIFI_RECONNECTING,
    WIFI_FALLBACK_SCAN,
    WIFI_FALLBACK_WAIT_SSID,
    WIFI_FALLBACK_WAIT_PASS,
    WIFI_FALLBACK_CONNECTING
};

struct WiFiSM {
    WiFiStato     stato         = WIFI_OK;
    int           tentativi     = 0;
    unsigned long tStato        = 0;
    String        nuovoSSID     = "";
    String        nuovaPassword = "";
} wifiSM;

// --- WIFI E FIREBASE ---
const char* ssid               = "LAPTOP1234";
const char* password           = "12345678";
const char* firebaseCmdUrl     = "https://serra-d44cc-default-rtdb.europe-west1.firebasedatabase.app/serra/commands.json";
const char* firebaseSensorsUrl = "https://serra-d44cc-default-rtdb.europe-west1.firebasedatabase.app/serra/sensors.json";

// --- SENSORE SHT45 ---
Adafruit_SHT4x sht45 = Adafruit_SHT4x();
bool sht45Ok = false;

// --- SERVO ---
Servo servoA;
Servo servoB;
const int servoAPin = 4;
const int servoBPin = 16;

// --- STATO TETTO (solo per LCD) ---
bool roofOpen = false;

// --- DHT11 ---
#define DHTPIN  5
#define DHTTYPE DHT11
DHT dht(DHTPIN, DHTTYPE);
unsigned long dhtReadyAt = 0;

// --- LCD I2C ---
#define LCD_ADDR 0x27
LiquidCrystal_I2C lcd(LCD_ADDR, 16, 2);

// --- TIMING ---
unsigned long lastSensorRead    = 0;
unsigned long lastDisplayUpdate = 0;
unsigned long lastSendData      = 0;
unsigned long lastCommandCheck  = 0;
unsigned long lastWifiCheck     = 0;

// --- CACHE ULTIMA LETTURA SENSORI ---
struct SensorData {
    float temperature;
    float humidity;
    int   soilMoisture;
    bool  valid;
};
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

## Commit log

2026-04-23 primo commit
    [SegmaSirra-B_Cu.gbr, SegmaSirra-B_Mask.gbr, SegmaSirra-B_Paste.gbr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]
2026-07-25 Reorganized project with new images
    [SegmaSirra-B_Cu.gbr, SegmaSirra-B_Mask.gbr, SegmaSirra-B_Paste.gbr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]

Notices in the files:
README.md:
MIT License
